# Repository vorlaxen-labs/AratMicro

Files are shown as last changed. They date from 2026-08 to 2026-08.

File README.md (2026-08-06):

# AratMicro

High-performance, open-source **micromouse** robot platform built for **[Robosam](https://robosam.org/)** and **MEB Robot** (Ministry of National Education Robotics Competition, Turkey).

AratMicro is a competition-focused maze-solving robot with a custom PCB, wall-detection sensors, dual-encoder drive, and STM32F411-based firmware. Hardware and software are developed together; all design files are shared in this repository.

## Competition target

This robot is designed to meet the maze-solving requirements of:

- **Robosam** — national robotics competition (micromouse / labyrinth category)
- **MEB Robot** — Ministry of National Education (MEB) robotics competition for schools

The mechanical dimensions, sensor layout, and control architecture are tuned for fast, reliable maze exploration and shortest-path solving under competition rules.

## Features

| Area | Detail |
|---|---|
| **MCU** | STM32F411CEU6 — Cortex-M4 @ 100 MHz, 512 KB Flash, 128 KB RAM |
| **Motor driver** | DRV8833 — dual-channel H-bridge |
| **Wall sensors** | 4× IR receivers + 4× IR LEDs (front left/right, left, right) |
| **Maze solver** | Flood fill (16×16 grid) |
| **Position feedback** | Left/right quadrature encoders (L_ENC_A/B, R_ENC_A/B) |
| **I/O expansion** | PCF8574AP — I2C GPIO expander |
| **Power** | 2S LiPo → AP63203WU buck (3.3 V logic), separate motor rail |
| **Programming** | ST-Link SWD (PA13/PA14), optional UART Bluetooth |
| **Firmware** | PlatformIO + Arduino framework, C++17 |

## Mechanical (target parts)

| Part | Size | Notes |
|---|---|---|
| **Motor** | 40 × 12 × 17 mm | 3 mm D-shaft |
| **Wheel** | 32 × 7 mm | 3 mm D-shaft |

> Mechanical CAD files are not yet included. Dimensions were chosen to match the PCB and drivetrain layout.

## Repository layout

```
AratMicro/
├── hardware/
│   └── pcb/          # KiCad 10 schematics and PCB (AratMicro.kicad_pro)
├── software/
│   ├── src/          # Firmware source code
│   ├── include/      # Public API headers
│   ├── lib/          # PlatformIO module libraries
│   ├── test/         # Host-side unit tests (Unity)
│   ├── docs/         # Architecture and hardware reference
│   └── platformio.ini
├── LICENSE
└── CONTRIBUTING.md
```

## Quick start

### Requirements

- [PlatformIO](https://platformio.org/) (VS Code extension or CLI)
- ST-Link V2 (or compatible programmer)
- KiCad 10.x (for hardware edits)

### Build and upload firmware

```bash
cd software
pio run -e aratmicro_f411
pio run -e aratmicro_f411 -t upload
```

### Host tests

Algorithms and core logic can be tested on the host:

```bash
cd software
pio test -e native
```

### Hardware

KiCad project: `hardware/pcb/AratMicro.kicad_pro`

Schematic sub-sheets:

| Sheet | File | Contents |
|---|---|---|
| Power Supply | `power_supply.kicad_sch` | 2S LiPo input, buck, protection |
| MCU | `mcu.kicad_sch` | STM32F411, clocks, SWD, I/O |
| Motor Controller | `mc.kicad_sch` | DRV8833 motor driver |
| Sensor Unit | `su.kicad_sch` | IR wall-detection circuit |

Full BOM and signal list: [`hardware/README.md`](hardware/README.md)

## Software architecture

Firmware is organized in layers:

- **core** — Hardware-independent application lifecycle
- **platform** — Time and pin abstractions
- **lib/** — Motor, IMU, maze solver modules (planned)

Details: [`software/docs/architecture.md`](software/docs/architecture.md)

## Status

| Component | Status |
|---|---|
| PCB schematic | Active development |
| PCB layout | Active development |
| Firmware skeleton | Available |
| Motor driver code | Planned |
| Wall sensor code | Planned |
| Maze solver (flood fill) | Available (host-tested) |
| Mechanical CAD | Planned |

## Contributing

Contributions are welcome. Please read [`CONTRIBUTING.md`](CONTRIBUTING.md).

## License

This project is released under the [MIT License](LICENSE) — hardware and software may be used, modified, and shared freely.

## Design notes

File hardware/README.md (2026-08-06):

# AratMicro — Hardware

KiCad 10 main board (PCB) design for the Robosam and MEB Robot micromouse platform. Project file: [`pcb/AratMicro.kicad_pro`](pcb/AratMicro.kicad_pro)

## Schematic hierarchy

```
AratMicro.kicad_sch
├── Power Supply/      power_supply.kicad_sch
├── MCU/               mcu.kicad_sch
├── Motor Controller Unit/   mc.kicad_sch
└── Sensor Unit/       su.kicad_sch
```

## Key components (BOM summary)

| Ref | Part | Description |
|-----|---|---|
| U2 | STM32F411CEU6 | Main MCU, UFQFPN-48 |
| U3 | DRV8833PWP | Dual H-bridge motor driver, HTSSOP-16 |
| U4 | PCF8574AP | I2C GPIO expander |
| U1 | AP63203WU | 2 A buck, fixed 3.3 V output |
| Y1 | 8 MHz crystal | HSE |
| Y2 | 32.768 kHz crystal | LSE (RTC) |
| BZ1 | Murata PKMCS0909E | Piezo buzzer |
| J (LiPo) | 2S LiPo connector | Battery input |

Protection: polyfuse, TVS diode, AO3401A P-channel MOSFET (power path).

## MCU signal map

Signal names are taken from schematic hierarchical labels. STM32 pin assignments will be finalized during PCB layout.

### Motor driver (DRV8833)

| Signal | Direction | Description |
|---|---|---|
| MC_IN1 | MCU → DRV | Motor A direction 1 |
| MC_IN2 | MCU → DRV | Motor A direction 2 |
| MC_BIN1 | MCU → DRV | Motor B direction 1 |
| MC_BIN2 | MCU → DRV | Motor B direction 2 |
| MC_SLEEP | MCU → DRV | Sleep / enable |
| MC_FAULT | DRV → MCU | Fault output |
| AOUT1, AOUT2 | DRV → motor | Motor A |
| BOUT1, BOUT2 | DRV → motor | Motor B |

### Encoders

| Signal | Description |
|---|---|
| L_ENC_A, L_ENC_B | Left wheel quadrature |
| R_ENC_A, R_ENC_B | Right wheel quadrature |

### Wall sensors (IR)

| Signal | Description |
|---|---|
| IR_ON | Enable IR LEDs (Sensor Unit) |
| REC_F_L | Front-left receiver |
| REC_F_R | Front-right receiver |
| REC_L | Left wall receiver |
| REC_R | Right wall receiver |

The Sensor Unit uses 4× IR receivers paired with 4× IR LEDs (one emitter per direction: front-left, front-right, left, right). LED drivers are controlled via BC817 NPN transistors.

### Other

| Signal | Description |
|---|---|
| SNIFF_SDA, SNIFF_SCL | I2C (IMU / external sensor bus) |
| BT_TX, BT_RX | UART — wireless module (optional) |
| Buzzer | Audio feedback |
| LED1–LED4 | Status LEDs |
| PA13, PA14 | SWD (ST-Link) |
| NRST, BOOT0 | Reset and boot mode |
| BATTS | Battery voltage (ADC) |

## Power architecture

```
2S LiPo (7.4 V nominal)
    │
    ├── Motor rail ──► DRV8833 VM
    │
    └── AP63203WU buck ──► +3.3 V logic
            │
            ├── STM32F411
            ├── PCF8574AP
            └── Sensor Unit (IR circuit)
```

Logic runs at 3.3 V; motor supply is driven directly from the battery rail. Polyfuse and TVS provide input protection.

## Mechanical interface

The drivetrain is designed for these off-the-shelf parts:

| Part | Size |
|---|---|
| DC motor | 40 × 12 × 17 mm, 3 mm D-shaft |
| Wheel | 32 × 7 mm, 3 mm D-shaft |

Motor connectors are defined on the Motor Controller Unit sheet.

## Opening in KiCad

1. Install KiCad 10.x.
2. Open `pcb/AratMicro.kicad_pro`.
3. Use the top-level hierarchy sheet in Eeschema to navigate sub-sheets.

## Fabrication

When PCB layout is complete:

- Export Gerber and drill files to `hardware/pcb/fabrication/`.
- BOM CSV: Eeschema → Tools → Generate Bill of Materials.

> **Note:** Layout and fabrication files are not final yet; the repository version is under active development.

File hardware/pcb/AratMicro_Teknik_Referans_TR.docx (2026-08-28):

AratMicro

Yüksek Performanslı Micromouse Robot Platformu

Alan | Değer
Belge Türü | Donanım ve Yazılım Teknik Referansı
Mikrodenetleyici | STM32F411CEU6
Güç Sistemi | 2S LiPo
PCB Mimarisi | 4 katmanlı özel PCB
Yazılım | PlatformIO + C++17

AratMicro; hızlı labirent keşfi, güvenilir duvar algılama, kapalı çevrim motor kontrolü ve en kısa yol çözümü için tasarlanmış yarış odaklı bir micromouse platformudur.

# 1. Sistem Genel Bakış

AratMicro, sensör, motor sürüşü, konum geri bildirimi, güç yönetimi ve gerçek zamanlı navigasyonu tek bir özel PCB üzerinde birleştiren kompakt bir micromouse sistemidir.

- 100 MHz ARM Cortex-M4 tabanlı STM32F411CEU6 kontrol birimi
- Çift N20 DC motor ve çift quadrature encoder geri bildirimi
- Dört kanallı IR duvar algılama sistemi
- LSM6DS3 IMU ile açısal hız ve hareket geri bildirimi
- 2S LiPo besleme ve AP63203 tabanlı 3.3 V logic rail
- Flood-fill tabanlı 16 x 16 labirent çözümü

# 2. Sistem Mimarisi

2S LiPo
|
+--> Motor Rail --> DRV8833 --> Sol / Sağ Motor
|
+--> AP63203 --> 3.3 V --> STM32F411CEU6
|--> IR Sensörler
|--> Encoderlar
|--> LSM6DS3 IMU
|--> UI / I2C

# 3. Ana İşlemci

Parametre | Değer
MCU | STM32F411CEU6
Çekirdek | ARM Cortex-M4
Maksimum saat | 100 MHz
Flash | 512 KB
SRAM | 128 KB
Logic gerilimi | 3.3 V
Debug / programlama | SWD
Paket | UFQFPN-48

MCU; motor PWM üretimi, quadrature encoder sayımı, ADC örnekleme, SPI/I2C haberleşmesi, batarya ölçümü ve gerçek zamanlı navigasyon görevlerini yürütür.

# 4. MCU Pin ve Periferik Eşlemesi

Pin | Periferik | Sinyal | Görev
PA0 | ADC | BATT_SENSE | Batarya gerilimi ölçümü
PA2 | USART | BT_TX | Bluetooth / telemetri TX
PA3 | USART | BT_RX | Bluetooth / telemetri RX
PA4 | ADC | IR_RECEIVER_F_R | Ön sağ IR alıcı
PA5 | ADC | IR_RECEIVER_F_L | Ön sol IR alıcı
PA6 | ADC | IR_RECEIVER_L | Sol IR alıcı
PA7 | ADC | IR_RECEIVER_R | Sağ IR alıcı
PA8 | PWM/GPIO | MC_IN1 | Motor sürücü giriş
PA9 | PWM/GPIO | MC_IN2 | Motor sürücü giriş
PA10 | PWM/GPIO | MC_BIN1 | Motor sürücü giriş
PA11 | PWM/GPIO | MC_BIN2 | Motor sürücü giriş
PA12 | EXTI | IMU_INT | IMU interrupt
PA13 | SWD | SWDIO | Programlama/debug
PA14 | SWD | SWCLK | Programlama/debug
PB0 | ADC | QTR_LEFT | Yardımcı optik giriş
PB1 | ADC | QTR_RIGHT | Yardımcı optik giriş
PB4 | Encoder | R_ENC_A | Sağ encoder A
PB5 | Encoder | R_ENC_B | Sağ encoder B
PB6 | Encoder | L_ENC_A | Sol encoder A
PB7 | Encoder | L_ENC_B | Sol encoder B
PB8 | I2C | SNIFF_SCL | I2C saat
PB9 | I2C | SNIFF_SDA | I2C veri
PB12 | SPI | IMU_CS | IMU chip select
PB13 | SPI | IMU_SCK | IMU saat
PB14 | SPI | IMU_MISO | IMU -> MCU
PB15 | SPI | IMU_MOSI | MCU -> IMU

# 5. Motor Kontrol Sistemi

AratMicro, iki fırçalı DC motoru DRV8833 çift H-köprü sürücü üzerinden kontrol eder. Sol ve sağ motorlar bağımsız PWM ve yön kontrolüne sahiptir.

Sinyal | MCU pini | İşlev
MC_IN1 | PA8 | Motor kanal A kontrolü
MC_IN2 | PA9 | Motor kanal A kontrolü
MC_BIN1 | PA10 | Motor kanal B kontrolü
MC_BIN2 | PA11 | Motor kanal B kontrolü

Yazılım tarafında motor sürücü GPIO seviyesinde kullanılmamalı; hız, yön, fren ve coast davranışları ayrı bir motor sürücü katmanı üzerinden yönetilmelidir.

MotorDriver
- setSpeed(left, right)
- setDirection(...)
- brake(...)
- coast(...)

# 6. Encoder Sistemi

Sinyal | MCU pini | Görev
R_ENC_A | PB4 | Sağ teker quadrature A
R_ENC_B | PB5 | Sağ teker quadrature B
L_ENC_A | PB6 | Sol teker quadrature A
L_ENC_B | PB7 | Sol teker quadrature B

- Teker hızının ölçülmesi
- Kat edilen mesafenin hesaplanması
- Sol/sağ motor senkronizasyonu
- Kapalı çevrim hız kontrolü
- Odometri ve dönüş doğrulaması

# 7. IR Duvar Algılama

Sistem dört adet IR receiver kanalı kullanır: ön sol, ön sağ, sol ve sağ. Receiver çıkışları STM32 ADC tarafından örneklenir.

Kanal | MCU pini
Ön sağ | PA4
Ön sol | PA5
Sol | PA6
Sağ | PA7

Önerilen ölçüm yöntemi, ortam ışığını bastırmak için emitter açık/kapalı fark ölçümüdür:

1. IR emitter OFF -> ambient sample
2. IR emitter ON
3. Kısa settling süresi
4. Illuminated sample
5. Signal = illuminated - ambient

IR emitter grupları yazılım tarafından zamanlamalı olarak sürülmeli; sürekli açık bırakılmamalıdır.

# 8. IMU

Sinyal | MCU pini | Görev
IMU_CS | PB12 | SPI chip select
IMU_SCK | PB13 | SPI clock
IMU_MISO | PB14 | IMU veri çıkışı
IMU_MOSI | PB15 | IMU veri girişi
IMU_INT | PA12 | Interrupt / data-ready

LSM6DS3; 90° dönüşlerin stabilizasyonu, yaw-rate kontrolü, dönüş bitiş tespiti ve encoder kaynaklı açısal hataların düzeltilmesi için kullanılabilir.

# 9. Güç Mimarisi

Alan | Değer
Batarya | 2S LiPo
Nominal gerilim | 7.4 V
Maksimum gerilim | 8.4 V
Logic rail | 3.3 V
Buck converter | AP63203WU
Motor sürücü | DRV8833

Motor rail ve logic rail ayrıdır. Logic beslemesi AP63203WU synchronous buck üzerinden 3.3 V'a regüle edilir.

2S LiPo -> AP63203WU -> 3.3 V -> MCU / sensörler

# 10. Batarya Ölçümü

Batarya gerilimi PA0 ADC girişinden ölçülür.

Eleman | Değer
Üst bölücü direnç | 10 kΩ
Alt bölücü direnç | 4.7 kΩ
ADC pini | PA0

Batarya gerilimi yaklaşık olarak şu bağıntıyla yeniden hesaplanır:

VBAT = VADC x (10 + 4.7) / 4.7 ≈ VADC x 3.1277

Tam dolu 2S LiPo (8.4 V) yaklaşık 2.69 V ADC seviyesine karşılık gelir ve 3.3 V ADC aralığı içinde kalır.

# 11. Programlama ve Haberleşme

Arayüz | Sinyaller / Pinler | Kullanım
SWD | PA13 SWDIO / PA14 SWCLK / NRST | Programlama ve debug
UART | PA2 TX / PA3 RX | Bluetooth, telemetri, PID tuning
I2C | PB8 SCL / PB9 SDA | Yardımcı çevre birimleri
SPI | PB12-PB15 | LSM6DS3 IMU

# 12. Firmware Mimarisi

Application
|-- Maze Solver
|-- Motion Controller
|-- Navigation / Odometry
|-- Sensor Processing
|
|-- Motor Driver
|-- Encoder Driver
|-- IR Sensor Driver
|-- IMU Driver
|-- Battery Monitor
|
`-- STM32 Hardware Layer

Donanım sürücüleri ile maze/navigation mantığı birbirinden ayrılmalıdır. Böylece PID, sensör okuma ve yol bulma algoritmaları bağımsız test edilebilir.

# 13. Gerçek Zamanlı Kontrol Akışı

Encoder oku
-> Gyro oku
-> IR sensörleri örnekle
-> Odometriyi güncelle
-> Hız / heading hatasını hesapla
-> PID hesapla
-> Motor PWM güncelle
-> Navigasyon durumunu güncelle

Motor/encoder/IMU kontrol döngüsü, maze solver ve telemetri gibi daha yavaş işlerden ayrı zamanlanmalıdır.

# 14. Navigasyon ve Maze Solver

AratMicro, 16 x 16 hücreli maze modeli üzerinde flood-fill tabanlı keşif ve en kısa yol çözümü için tasarlanmıştır.

- Duvar haritasının tutulması
- Robotun X/Y hücre konumunun izlenmesi
- Robot heading bilgisinin tutulması
- Hücre maliyetlerinin flood-fill ile güncellenmesi
- Keşif koşusu ve hızlı koşunun mantıksal olarak ayrılması

EXPLORE
-> Wall map oluştur
-> Hedefe ulaş
-> Optimize edilmiş rota hesapla
-> FAST RUN

# 15. Hareket Kontrolü

En güvenilir hareket kontrolü encoder, gyro ve duvar sensörlerinin birlikte değerlendirilmesiyle elde edilir.

Encoder -> mesafe / teker hızı
Gyro -> açısal hız / dönüş kontrolü
IR -> labirente göre lateral düzeltme

Hepsi birlikte -> motion estimation -> closed-loop drive

# 16. 4 Katmanlı PCB Mimarisi

Katman | Önerilen kullanım
L1 - F.Cu | Komponentler, kritik sinyaller, kısa güç yolları
L2 - In1.Cu | Mümkün olduğunca kesintisiz GND plane
L3 - In2.Cu | 3V3 / BATT güç dağıtımı
L4 - B.Cu | Yardımcı sinyaller

Kart fiziksel olarak IR sensör bölgesi, MCU/logic bölgesi, motor driver bölgesi, switching regulator bölgesi ve batarya/yüksek akım bölgesi şeklinde düşünülmelidir.

# 17. İlk Açılış / Bring-Up

- İlk enerjilendirmede motorlar bağlanmadan 3.3 V rail doğrulanmalı.
- SWD üzerinden MCU erişimi ve NRST doğrulanmalı.
- BATT_SENSE ADC değeri gerçek multimetre ölçümüyle kalibre edilmeli.
- IR kanalları tek tek okunmalı ve emitter açık/kapalı farkı doğrulanmalı.
- Encoder A/B yönleri teker dönüş yönüyle karşılaştırılmalı.
- Motor yönleri firmware tarafında sol/sağ koordinat sistemine göre sabitlenmeli.
- IMU eksen yönleri robot koordinat sistemiyle eşleştirilmeli.

# 18. Sistem Özeti

Alt Sistem | Konfigürasyon
İşlemci | STM32F411CEU6, Cortex-M4, 100 MHz
Motor sürüş | DRV8833 + 2 x N20 DC motor
Konum geri bildirimi | 2 x quadrature encoder
Duvar algılama | 4 x IR receiver + 4 x IR emitter
IMU | LSM6DS3, SPI
Güç | 2S LiPo + AP63203WU 3.3 V buck
Batarya ölçümü | PA0 ADC
Navigasyon | 16 x 16 flood-fill
Programlama | ST-Link SWD
Firmware | PlatformIO + C++17

AratMicro - Donanım ve Yazılım Teknik Referansı

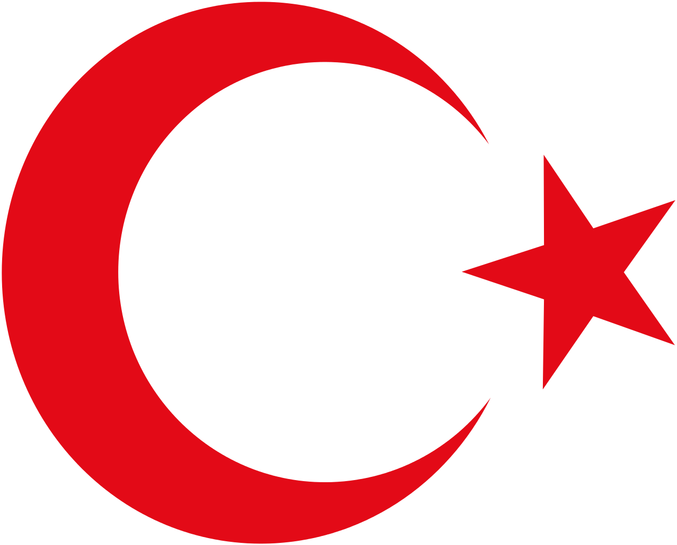
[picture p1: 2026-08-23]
hardware/resources/images/tr-flag.png

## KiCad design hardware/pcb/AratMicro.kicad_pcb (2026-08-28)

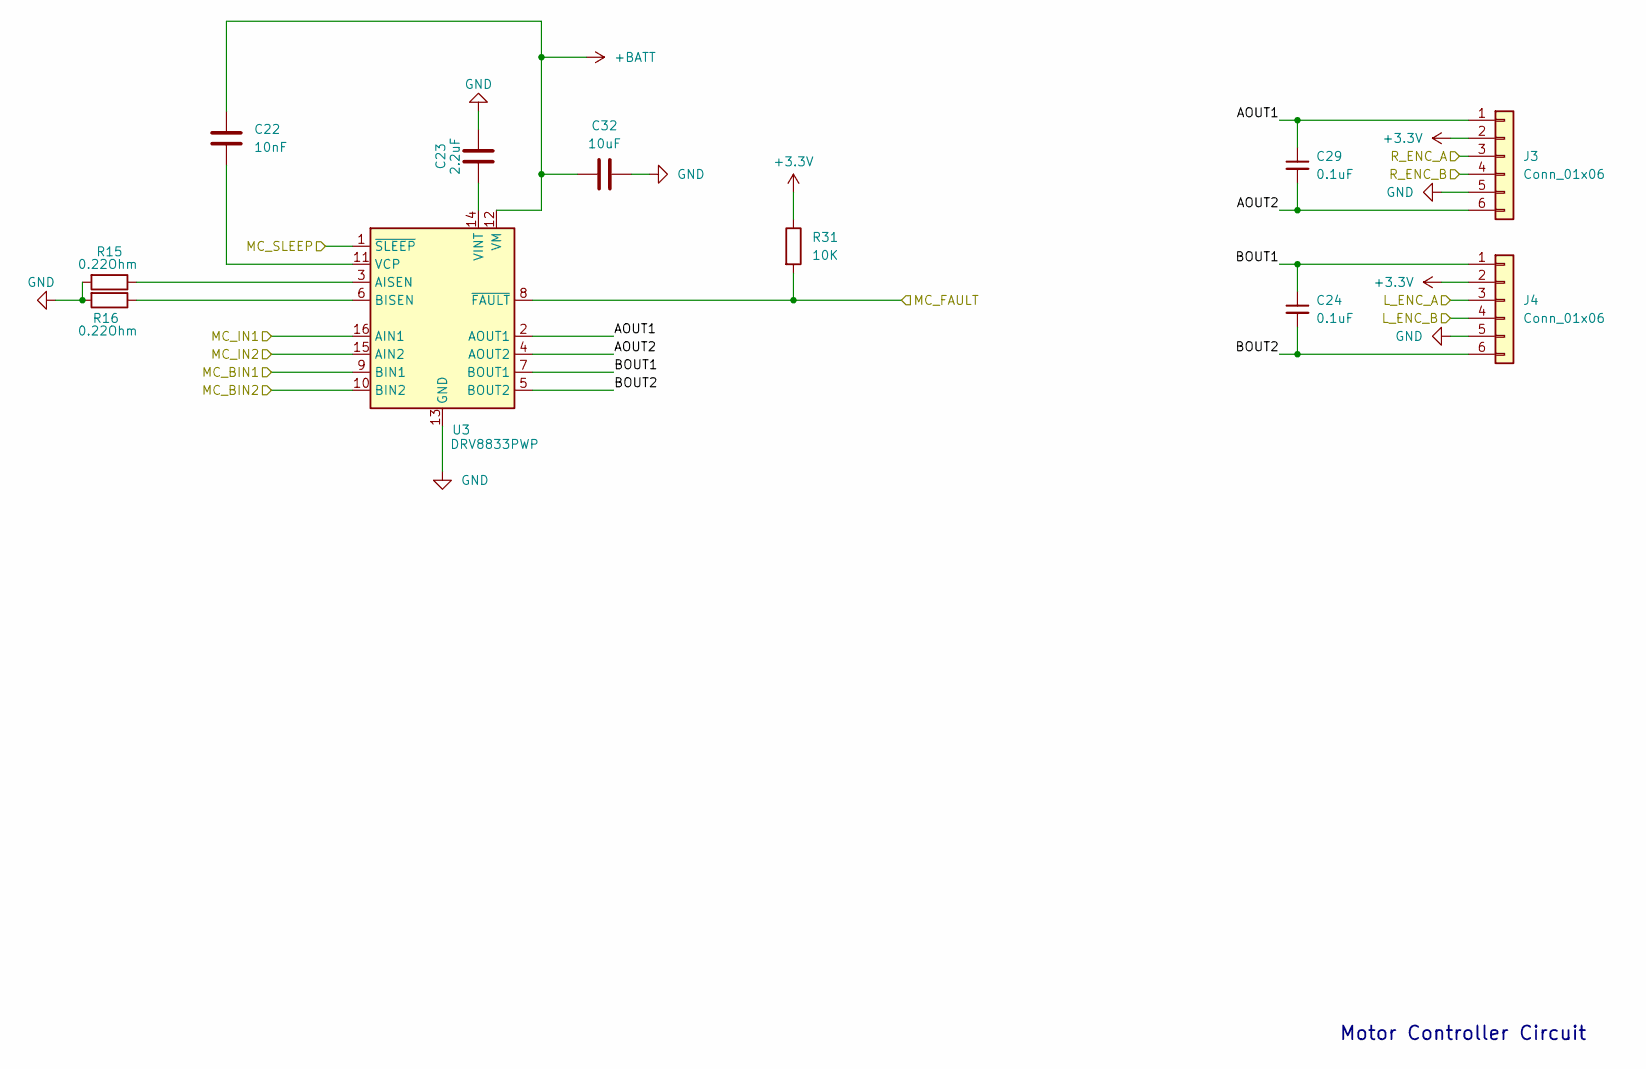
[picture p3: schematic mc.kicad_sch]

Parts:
C22: 10nF; C_0603_1608Metric
C23: 2.2uF; C_0603_1608Metric
C24, C29: 0.1uF; C_0603_1608Metric
C32: 10uF; C_0805_2012Metric
J3, J4: Conn_01x06; PinHeader_1x06_P2.54mm_Vertical
R15, R16: 0.22Ohm; R_0805_2012Metric
R31: 10K; R_0603_1608Metric
U3: DRV8833PWP; HTSSOP-16-1EP_4.4x5mm_P0.65mm_EP3.4x5mm_Mask2.46x2.31mm_The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

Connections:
+3.3V: J3.2, J4.2, R31.1; also elsewhere on the board
+BATT: C22.1, C32.1, U3.12 (VM); also elsewhere on the board
/Microcontroller Unit/L_ENC_A: J4.3; also elsewhere on the board
/Microcontroller Unit/L_ENC_B: J4.4; also elsewhere on the board
/Microcontroller Unit/MC_BIN1: U3.9 (BIN1); also elsewhere on the board
/Microcontroller Unit/MC_BIN2: U3.10 (BIN2); also elsewhere on the board
/Microcontroller Unit/MC_FAULT: R31.2, U3.8 (~FAULT); also elsewhere on the board
/Microcontroller Unit/MC_IN1: U3.16 (AIN1); also elsewhere on the board
/Microcontroller Unit/MC_IN2: U3.15 (AIN2); also elsewhere on the board
/Microcontroller Unit/MC_SLEEP: U3.1 (~SLEEP); also elsewhere on the board
/Microcontroller Unit/R_ENC_A: J3.3; also elsewhere on the board
/Microcontroller Unit/R_ENC_B: J3.4; also elsewhere on the board
/Motor Controller/AOUT1: C29.1, J3.1, U3.2 (AOUT1)
/Motor Controller/AOUT2: C29.2, J3.6, U3.4 (AOUT2)
/Motor Controller/BOUT1: C24.1, J4.1, U3.7 (BOUT1)
/Motor Controller/BOUT2: C24.2, J4.6, U3.5 (BOUT2)
GND: C23.2, C32.2, J3.5, J4.5, R15.2, R16.2, U3.13 (GND), U3.17 (GND); also elsewhere on the board
unnamed: R15.1, U3.3 (AISEN)
unnamed: R16.1, U3.6 (BISEN)
unnamed: C22.2, U3.11 (VCP)
unnamed: C23.1, U3.14 (VINT)

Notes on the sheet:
Motor Controller Circuit

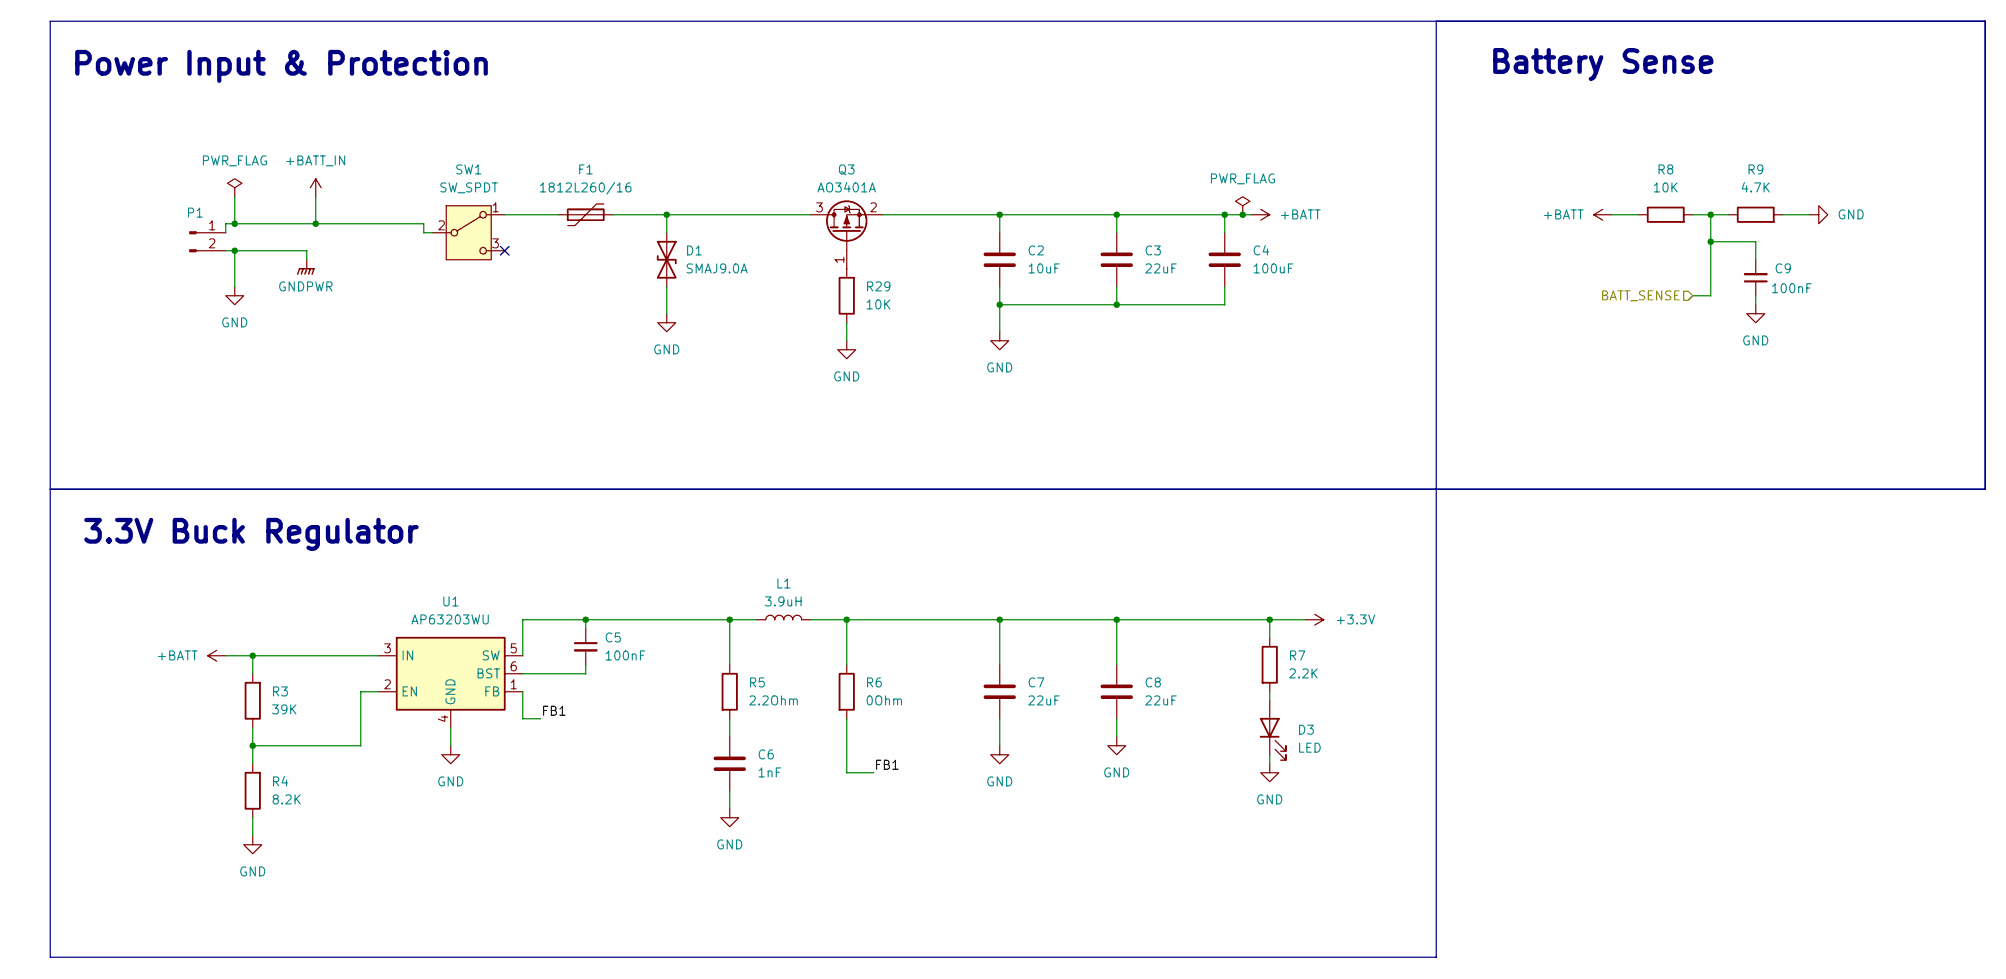
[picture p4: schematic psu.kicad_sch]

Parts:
C2: 10uF; C_0805_2012Metric
C3: 22uF; C_1206_3216Metric
C4: 100uF; C_1206_3216Metric
C5, C9: 100nF; C_0603_1608Metric
C6: 1nF; C_0603_1608Metric
C7: 22uF; C_0805_2012Metric_Pad1.18x1.45mm
C8: 22uF; C_0805_2012Metric
D1: SMAJ9.0A; D_SMA
D3: LED; LED_0603_1608Metric
F1: 1812L260/16; Fuse_1812_4532Metric
L1: 3.9uH; L_Sunlord_SWPA4030S
P1: 2S LiPo Connector; PinHeader_1x02_P2.54mm_Vertical
Q3: AO3401A; SOT-23
R3: 39K; R_0603_1608Metric
R4: 8.2K; R_0603_1608Metric
R5: 2.2Ohm; R_1206_3216Metric_Pad1.30x1.75mm_HandSolder
R6: 0Ohm; R_0603_1608Metric
R7: 2.2K; R_0603_1608Metric
R8, R29: 10K; R_0603_1608Metric
R9: 4.7K; R_0603_1608Metric
SW1: SW_SPDT; SW_SPDT_PCM12
U1: AP63203WU; TSOT-23-6

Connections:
+3.3V: C7.1, C8.1, L1.2, R6.1, R7.1; also elsewhere on the board
+BATT: C2.1, C3.1, C4.1, Q3.2 (S), R3.2, R8.1, U1.3 (IN); also elsewhere on the board
+BATT_IN: P1.1, SW1.2 (B)
/Microcontroller Unit/BATT_SENSE: C9.2, R8.2, R9.1; also elsewhere on the board
/Power Supply/FB1: R6.2, U1.1 (FB)
GND: C2.2, C3.2, C4.2, C6.2, C7.2, C8.2, C9.1, D1.2 (A2), D3.1 (K), P1.2, R4.1, R9.2, R29.1, U1.4 (GND); also elsewhere on the board
unnamed: C6.1, R5.2
unnamed: D1.1 (A1), F1.2, Q3.3 (D)
unnamed: D3.2 (A), R7.2
unnamed: Q3.1 (G), R29.2
unnamed: F1.1, SW1.1 (A)
unnamed: C5.2, U1.6 (BST)
unnamed: R3.1, R4.2, U1.2 (EN)
unnamed: C5.1, L1.1, R5.1, U1.5 (SW)

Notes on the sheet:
3.3V Buck Regulator
Battery Sense
Power Input & Protection

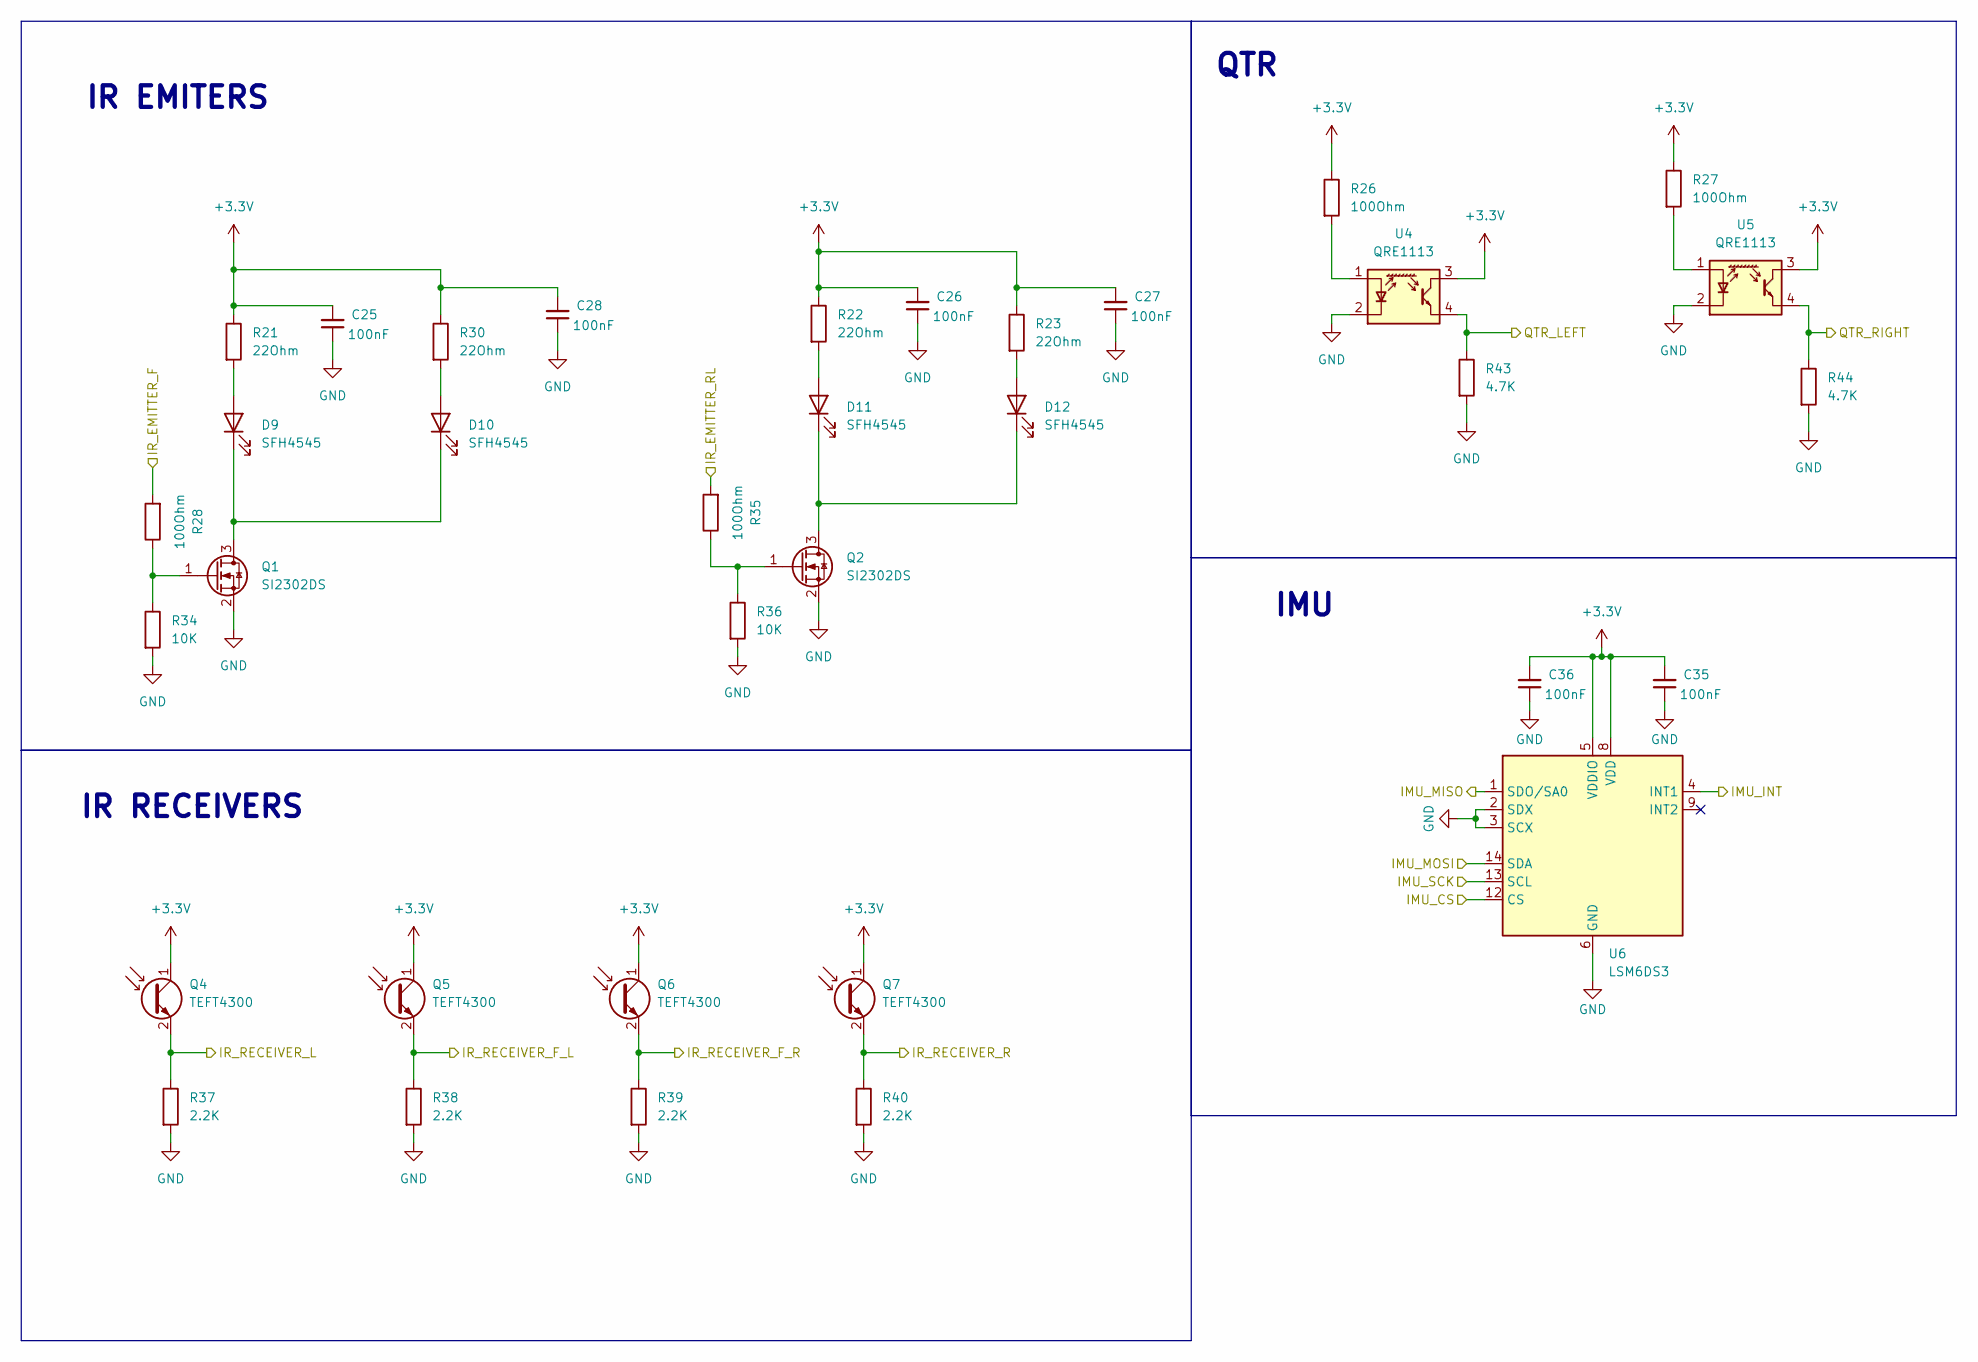
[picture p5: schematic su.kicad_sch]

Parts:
C25, C26, C27, C28, C35, C36: 100nF; C_0603_1608Metric
D9, D10, D11, D12: SFH4545; LED_D5.0mm_Horizontal_O1.27mm_Z15.0mm
Q1, Q2: SI2302DS; SOT-23
Q4, Q5, Q6, Q7: TEFT4300; LED_D3.0mm_IRBlack
R21, R22, R23, R30: 22Ohm; R_1206_3216Metric
R26, R27, R28, R35: 100Ohm; R_0603_1608Metric
R34, R36: 10K; R_0603_1608Metric
R37, R38, R39, R40: 2.2K; R_0603_1608Metric
R43, R44: 4.7K; R_0603_1608Metric
U4, U5: QRE1113; OnSemi_CASE100AQ
U6: LSM6DS3; LGA-14_3x2.5mm_P0.5mm_LayoutBorder3x4y

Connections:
+3.3V: C25.2, C26.2, C27.2, C28.2, C35.2, C36.2, Q4.1 (C), Q5.1 (C), Q6.1 (C), Q7.1 (C), R21.1, R22.1, R23.1, R26.1, R27.1, R30.1, U4.3, U5.3, U6.5 (VDDIO), U6.8 (VDD); also elsewhere on the board
/Microcontroller Unit/IMU_CS: U6.12 (CS); also elsewhere on the board
/Microcontroller Unit/IMU_INT: U6.4 (INT1); also elsewhere on the board
/Microcontroller Unit/IMU_MISO: U6.1 (SDO/SA0); also elsewhere on the board
/Microcontroller Unit/IMU_MOSI: U6.14 (SDA); also elsewhere on the board
/Microcontroller Unit/IMU_SCK: U6.13 (SCL); also elsewhere on the board
/Microcontroller Unit/IR_EMITTER_F: R28.2; also elsewhere on the board
/Microcontroller Unit/IR_EMITTER_RL: R35.2; also elsewhere on the board
/Microcontroller Unit/IR_RECEIVER_F_L: Q5.2 (E), R38.1; also elsewhere on the board
/Microcontroller Unit/IR_RECEIVER_F_R: Q6.2 (E), R39.1; also elsewhere on the board
/Microcontroller Unit/IR_RECEIVER_L: Q4.2 (E), R37.1; also elsewhere on the board
/Microcontroller Unit/IR_RECEIVER_R: Q7.2 (E), R40.1; also elsewhere on the board
/Microcontroller Unit/QTR_LEFT: R43.1, U4.4; also elsewhere on the board
/Microcontroller Unit/QTR_RIGHT: R44.1, U5.4; also elsewhere on the board
GND: C25.1, C26.1, C27.1, C28.1, C35.1, C36.1, Q1.2 (S), Q2.2 (S), R34.2, R36.2, R37.2, R38.2, R39.2, R40.2, R43.2, R44.2, U4.2 (K), U5.2 (K), U6.2 (SDX), U6.3 (SCX), U6.6 (GND), U6.7 (GND); also elsewhere on the board
unnamed: D9.2 (A), R21.2
unnamed: D10.2 (A), R30.2
unnamed: D9.1 (K), D10.1 (K), Q1.3 (D)
unnamed: D11.2 (A), R22.2
unnamed: D11.1 (K), D12.1 (K), Q2.3 (D)
unnamed: D12.2 (A), R23.2
unnamed: Q1.1 (G), R28.1, R34.1
unnamed: Q2.1 (G), R35.1, R36.1
unnamed: R26.2, U4.1 (A)
unnamed: R27.2, U5.1 (A)

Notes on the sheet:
IMU
IR EMITERS
QTR
IR RECEIVERS

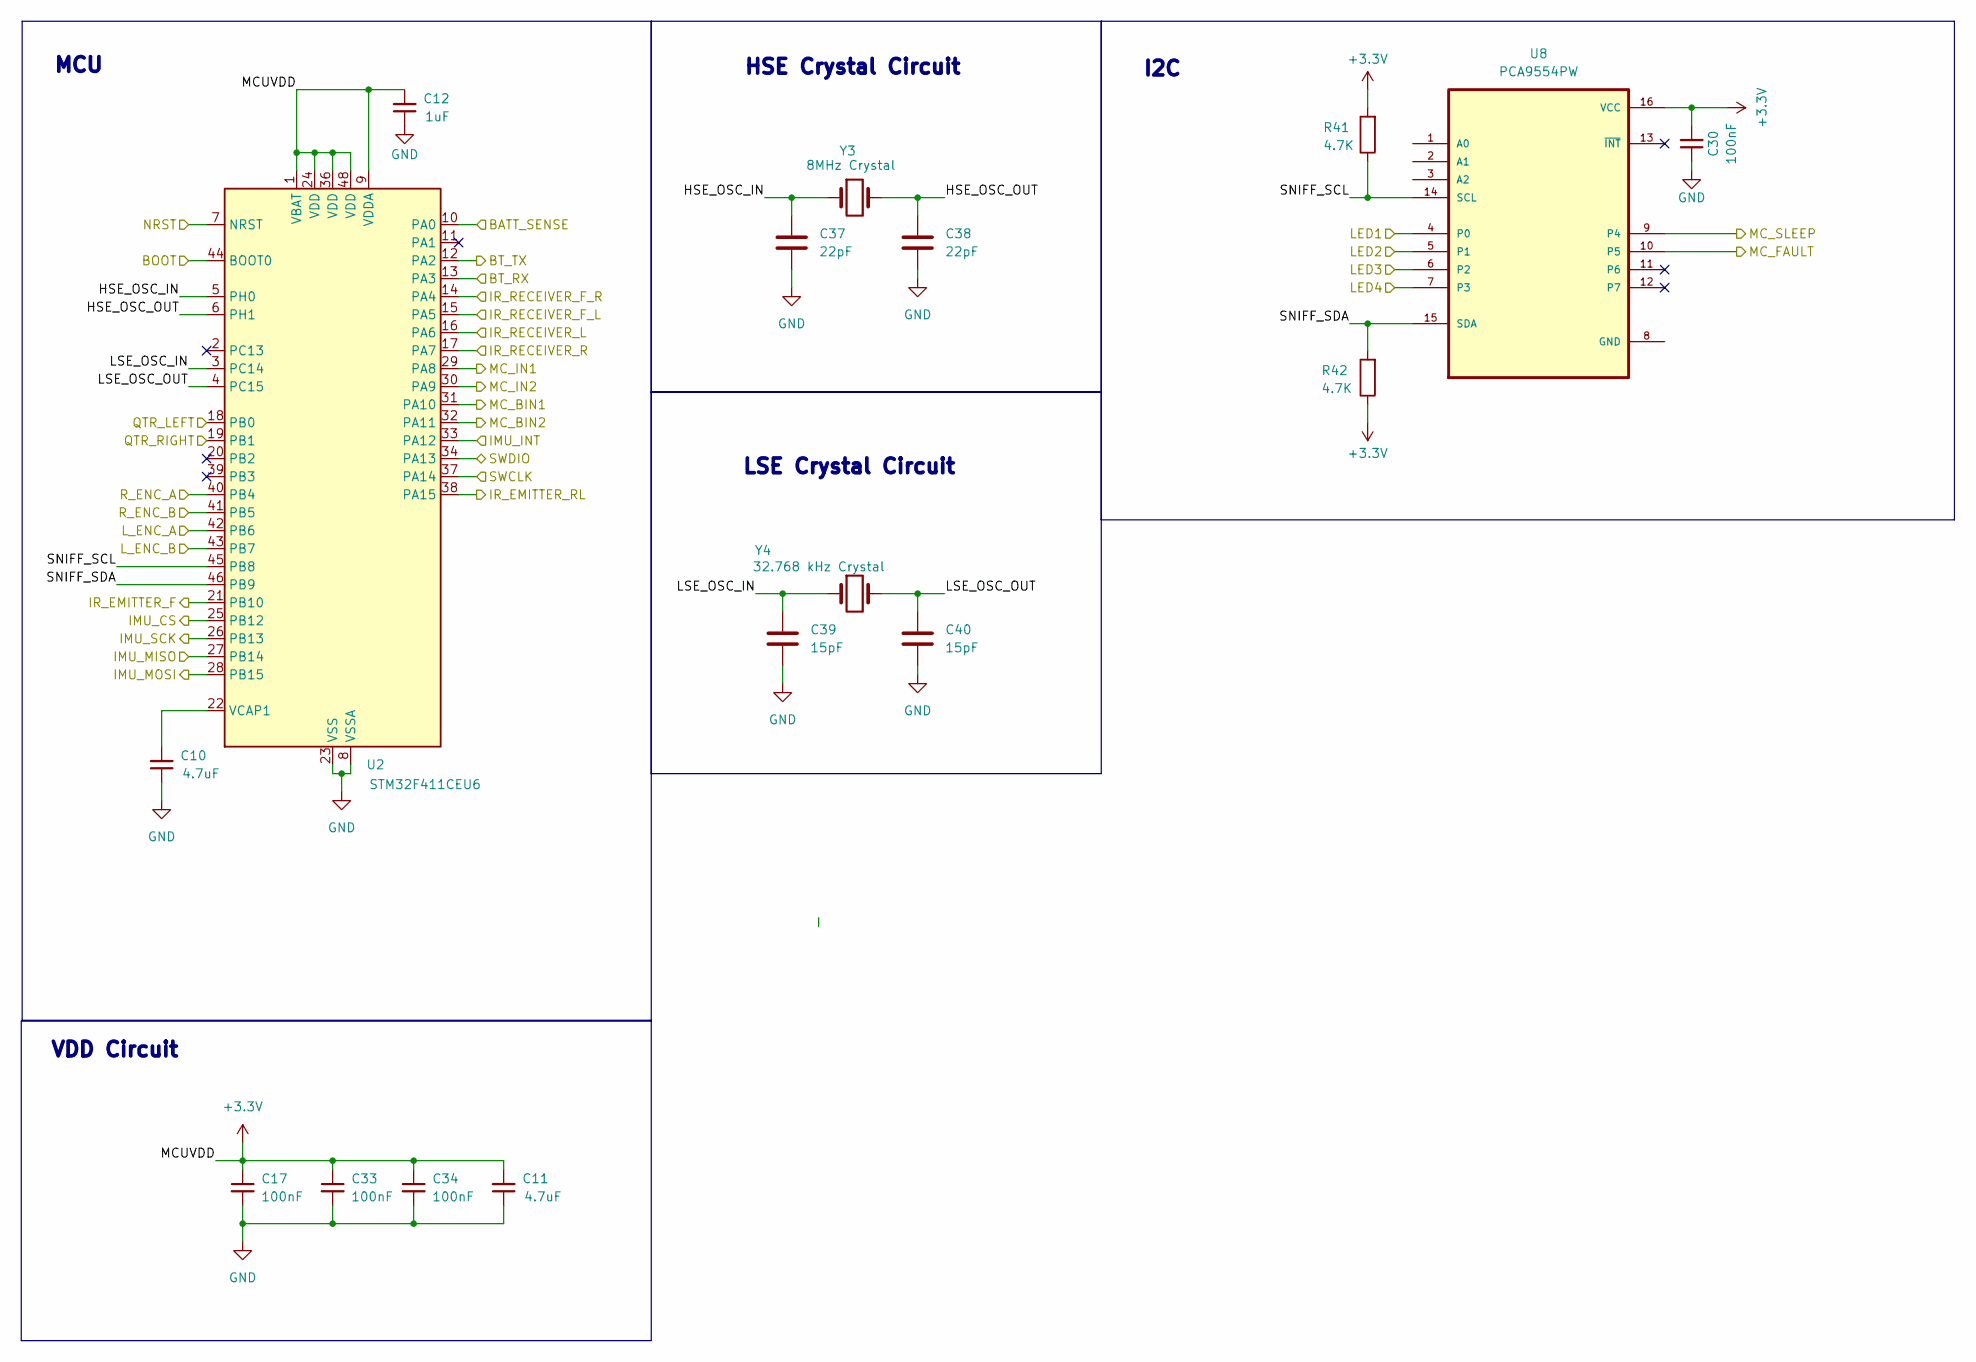
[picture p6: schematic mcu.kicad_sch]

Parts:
C10, C11: 4.7uF; C_0805_2012Metric
C12: 1uF; C_0603_1608Metric
C17, C30, C33, C34: 100nF; C_0603_1608Metric
C37, C38: 22pF; C_0603_1608Metric
C39, C40: 15pF; C_0603_1608Metric
R41, R42: 4.7K; R_0603_1608Metric
U2: STM32F411CEU6; QFN-48-1EP_7x7mm_P0.5mm_EP5.6x5.6mm
U8: PCA9554PW; SOP65P640X120-16N; DigiKey_Part_Number 2156-PCA9554PW-ND
Y3: 8MHz Crystal; Crystal_SMD_3225-4Pin_3.2x2.5mm_HandSoldering
Y4: 32.768 kHz Crystal; Crystal_SMD_3225-4Pin_3.2x2.5mm_HandSoldering

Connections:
+3.3V: C11.2, C12.2, C17.1, C30.2, C33.1, C34.1, R41.2, R42.1, U2.1 (VBAT), U2.9 (VDDA), U2.24 (VDD), U2.36 (VDD), U2.48 (VDD), U8.16 (VCC); also elsewhere on the board
/Microcontroller Unit/BATT_SENSE: U2.10 (PA0); also elsewhere on the board
/Microcontroller Unit/BOOT: U2.44 (BOOT0); also elsewhere on the board
/Microcontroller Unit/BT_RX: U2.13 (PA3); also elsewhere on the board
/Microcontroller Unit/BT_TX: U2.12 (PA2); also elsewhere on the board
/Microcontroller Unit/HSE_OSC_IN: C37.1, U2.5 (PH0), Y3.1
/Microcontroller Unit/HSE_OSC_OUT: C38.1, U2.6 (PH1), Y3.2
/Microcontroller Unit/IMU_CS: U2.25 (PB12); also elsewhere on the board
/Microcontroller Unit/IMU_INT: U2.33 (PA12); also elsewhere on the board
/Microcontroller Unit/IMU_MISO: U2.27 (PB14); also elsewhere on the board
/Microcontroller Unit/IMU_MOSI: U2.28 (PB15); also elsewhere on the board
/Microcontroller Unit/IMU_SCK: U2.26 (PB13); also elsewhere on the board
/Microcontroller Unit/IR_EMITTER_F: U2.21 (PB10); also elsewhere on the board
/Microcontroller Unit/IR_EMITTER_RL: U2.38 (PA15); also elsewhere on the board
/Microcontroller Unit/IR_RECEIVER_F_L: U2.15 (PA5); also elsewhere on the board
/Microcontroller Unit/IR_RECEIVER_F_R: U2.14 (PA4); also elsewhere on the board
/Microcontroller Unit/IR_RECEIVER_L: U2.16 (PA6); also elsewhere on the board
/Microcontroller Unit/IR_RECEIVER_R: U2.17 (PA7); also elsewhere on the board
/Microcontroller Unit/LED1: U8.4 (P0); also elsewhere on the board
/Microcontroller Unit/LED2: U8.5 (P1); also elsewhere on the board
/Microcontroller Unit/LED3: U8.6 (P2); also elsewhere on the board
/Microcontroller Unit/LED4: U8.7 (P3); also elsewhere on the board
/Microcontroller Unit/LSE_OSC_IN: C39.1, U2.3 (PC14), Y4.1
/Microcontroller Unit/LSE_OSC_OUT: C40.1, U2.4 (PC15), Y4.2
/Microcontroller Unit/L_ENC_A: U2.42 (PB6); also elsewhere on the board
/Microcontroller Unit/L_ENC_B: U2.43 (PB7); also elsewhere on the board
/Microcontroller Unit/MC_BIN1: U2.31 (PA10); also elsewhere on the board
/Microcontroller Unit/MC_BIN2: U2.32 (PA11); also elsewhere on the board
/Microcontroller Unit/MC_FAULT: U8.10 (P5); also elsewhere on the board
/Microcontroller Unit/MC_IN1: U2.29 (PA8); also elsewhere on the board
/Microcontroller Unit/MC_IN2: U2.30 (PA9); also elsewhere on the board
/Microcontroller Unit/MC_SLEEP: U8.9 (P4); also elsewhere on the board
/Microcontroller Unit/NRST: U2.7 (NRST); also elsewhere on the board
/Microcontroller Unit/QTR_LEFT: U2.18 (PB0); also elsewhere on the board
/Microcontroller Unit/QTR_RIGHT: U2.19 (PB1); also elsewhere on the board
/Microcontroller Unit/R_ENC_A: U2.40 (PB4); also elsewhere on the board
/Microcontroller Unit/R_ENC_B: U2.41 (PB5); also elsewhere on the board
/Microcontroller Unit/SNIFF_SCL: R41.1, U2.45 (PB8), U8.14 (SCL)
/Microcontroller Unit/SNIFF_SDA: R42.2, U2.46 (PB9), U8.15 (SDA)
/Microcontroller Unit/SWCLK: U2.37 (PA14); also elsewhere on the board
/Microcontroller Unit/SWDIO: U2.34 (PA13); also elsewhere on the board
GND: C10.1, C11.1, C12.1, C17.2, C30.1, C33.2, C34.2, C37.2, C38.2, C39.2, C40.2, U2.8 (VSSA), U2.23 (VSS), U2.35 (VSS), U2.47 (VSS), U2.49 (VSS); also elsewhere on the board
unnamed: C10.2, U2.22 (VCAP1)

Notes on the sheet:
VDD Circuit
HSE Crystal Circuit
MCU
I2C
LSE Crystal Circuit

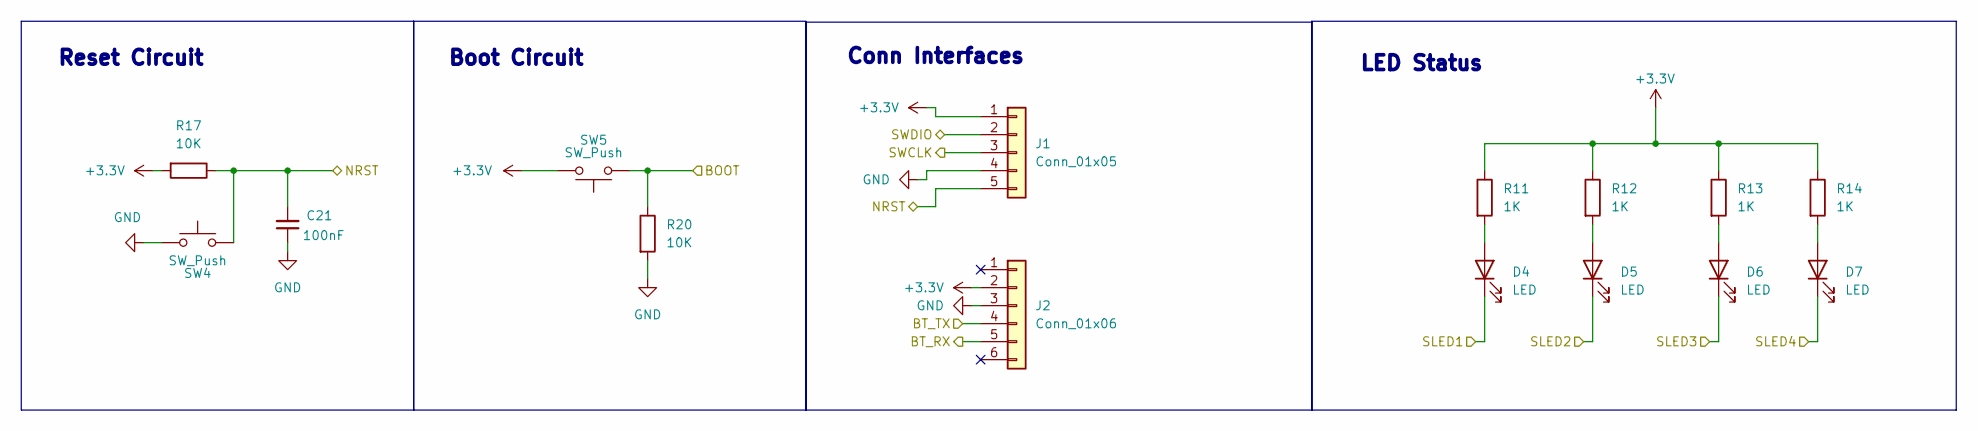
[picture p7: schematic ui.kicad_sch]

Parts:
C21: 100nF; C_0603_1608Metric
D4, D5, D6, D7: LED; LED_0603_1608Metric
J1: Conn_01x05; PinHeader_1x05_P1.00mm_Vertical
J2: Conn_01x06; PinHeader_1x06_P1.00mm_Vertical
R11, R12, R13, R14: 1K; R_0603_1608Metric
R17, R20: 10K; R_0603_1608Metric
SW4, SW5: SW_Push; SW_SPST_B3U-3000P

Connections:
+3.3V: J1.1, J2.2, R11.1, R12.1, R13.1, R14.1, R17.2, SW5.2; also elsewhere on the board
/Microcontroller Unit/BOOT: R20.1, SW5.1; also elsewhere on the board
/Microcontroller Unit/BT_RX: J2.5; also elsewhere on the board
/Microcontroller Unit/BT_TX: J2.4; also elsewhere on the board
/Microcontroller Unit/LED1: D4.1 (K); also elsewhere on the board
/Microcontroller Unit/LED2: D5.1 (K); also elsewhere on the board
/Microcontroller Unit/LED3: D6.1 (K); also elsewhere on the board
/Microcontroller Unit/LED4: D7.1 (K); also elsewhere on the board
/Microcontroller Unit/NRST: C21.2, J1.5, R17.1, SW4.2; also elsewhere on the board
/Microcontroller Unit/SWCLK: J1.3; also elsewhere on the board
/Microcontroller Unit/SWDIO: J1.2; also elsewhere on the board
GND: C21.1, J1.4, J2.3, R20.2, SW4.1; also elsewhere on the board
unnamed: D4.2 (A), R11.2
unnamed: D5.2 (A), R12.2
unnamed: D6.2 (A), R13.2
unnamed: D7.2 (A), R14.2

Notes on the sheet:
LED Status
Conn Interfaces
Reset Circuit
Boot Circuit

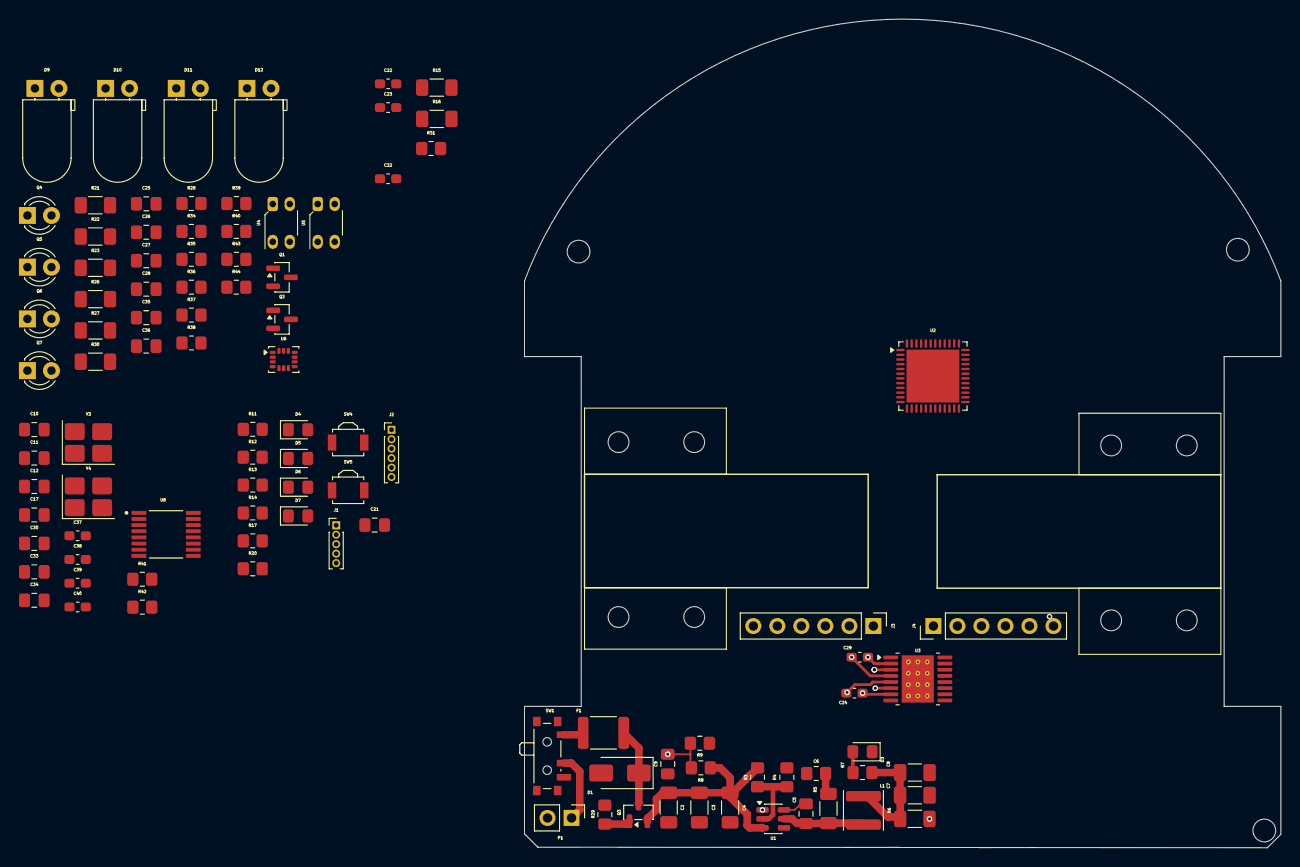
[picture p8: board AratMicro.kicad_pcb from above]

Board: 4 copper layers, 80.0 x 87.6 mm, 102 parts (0 on the bottom side), 76 nets.

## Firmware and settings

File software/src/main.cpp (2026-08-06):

#include "aratmicro/core/application.hpp"

#if defined(ARDUINO)
#include <Arduino.h>
#endif

namespace {

aratmicro::core::Application g_application;

}  // namespace

#if defined(ARDUINO)

void setup() {
  const auto result = g_application.initialize();
  (void)result;
}

void loop() {
  (void)g_application.tick();
}

#endif

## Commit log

2026-08-06 README sensor update!
2026-08-23 hardware: freeze schematic v1 after complete PCB redesign
    Complete PCB and schematic refresh with reorganized sheets (psu, ui),
    updated MCU/motor/sensor subsystems, and v1 schematic baseline frozen.
    [AratMicro.kicad_pcb, AratMicro.kicad_sch, mcu.kicad_sch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]
2026-08-28 format öncesi commit
    [AratMicro.kicad_pcb, AratMicro.kicad_sch, mc.kicad_sch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]
